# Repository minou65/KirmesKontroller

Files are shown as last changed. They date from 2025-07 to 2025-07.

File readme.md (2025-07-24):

# Kirmes kontroller
- [Kirmes kontroller](#kirmes-kontroller)
	- [Beschreibung](#beschreibung)
		- [Hauptfunktionen](#hauptfunktionen)
		- [Technische Spezifikationen](#technische-spezifikationen)
	- [Anschlüsse](#anschlüsse)
		- [Klemmenblöcke](#klemmenblöcke)
		- [Jumper-Einstellungen](#jumper-einstellungen)
	- [Controller](#controller)
	- [Librarys](#librarys)
	- [Pin mapping](#pin-mapping)
	- [internal pins](#internal-pins)
	- [external pins](#external-pins)
	- [Schema](#schema)
	- [Board](#board)
		- [Notwendige Änderungen auf v1 board](#notwendige-änderungen-auf-v1-board)
	- [Partliste](#partliste)
	- [Audio-Wiedergabe](#audio-wiedergabe)
		- [Unterstützte Audioformate](#unterstützte-audioformate)
		- [SD-Karte Setup](#sd-karte-setup)
		- [Kirmes-Sounds Quellen](#kirmes-sounds-quellen)
		- [Sounddateien bearbeiten](#sounddateien-bearbeiten)
			- [Online-Audio-Editoren](#online-audio-editoren)
			- [Desktop-Software](#desktop-software)
			- [Bearbeitungs-Tipps für Kirmes-Sounds](#bearbeitungs-tipps-für-kirmes-sounds)
			- [Batch-Verarbeitung](#batch-verarbeitung)
	- [Konfiguration](#konfiguration)
		- [System-Konfiguration](#system-konfiguration)
			- [System Configuration](#system-configuration)
			- [Sound Settings](#sound-settings)
			- [ServoOutput Konfiguration](#servooutput-konfiguration)
			- [Output Konfiguration](#output-konfiguration)
			- [Bedienelemente](#bedienelemente)
			- [Navigation](#navigation)
	- [WiFi](#wifi)
		- [Standard-Passwort](#standard-passwort)
		- [Standard-IP-Adresse](#standard-ip-adresse)
		- [OTA (Over-The-Air Updates)](#ota-over-the-air-updates)
		- [Konfigurationsoptionen](#konfigurationsoptionen)
		- [Blinkcodes](#blinkcodes)
	- [Firmware](#firmware)
		- [Firmware-Update über Web-Interface](#firmware-update-über-web-interface)
		- [Firmware-Update über OTA](#firmware-update-über-ota)
	- [Reset](#reset)
		- [Reset-Vorgang](#reset-vorgang)

## Beschreibung

Der KirmesKontroller ist ein vielseitiger NMRA-DCC-Decoder, der speziell für Kirmes- und Karussell-Anwendungen entwickelt wurde. Basierend auf dem leistungsstarken YB-ESP32-S3-AMP Mikrocontroller, bietet er umfangreiche Steuerungs- und Audio-Funktionen.

### Hauptfunktionen

**Ausgänge:**

- 8 digitale Ausgänge für Beleuchtung, Motoren und Effekte
- 3 Servo-Ausgänge für präzise Bewegungssteuerung
- Maximale Belastung: 500mA pro Ausgang

**Eingänge:**

- 2 digitale Eingänge für Taster- und Sensorfunktionen
- Manueller Betrieb unabhängig vom DCC-Signal möglich

**Konnektivität:**

- WiFi-Access-Point für direkten Zugriff
- Integration in bestehende WiFi-Netzwerke
- Web-basierte Konfigurationsoberfläche
- Over-The-Air (OTA) Updates

**Steuerungsmöglichkeiten:**

- **DCC-Kommandos:** Standard NMRA-DCC-Protokoll
- **Web-Interface:** Browserbasierte Steuerung
- **Digitale Eingänge:** Lokale Taster und Sensoren

**Audio-System:**

- Integrierte I2S-Audio-Wiedergabe
- SD-Karten-Unterstützung für Sounddateien
- Vielfältige Audioformate (MP3, WAV, FLAC, etc.)

### Technische Spezifikationen

**Stromversorgung:**

- **DC-Betrieb:** 8-28V Gleichspannung
- **AC-Betrieb:** 18-36V Wechselspannung
- **Ausgangsleistung:** 500mA pro Kanal
- **Wichtiger Hinweis:** Bei Jumper J1 auf Position "5V" darf der Gesamtstrom 1A nicht überschreiten

**Abmessungen und Anschlüsse:**

- Kompakte Bauform für einfache Integration
- Schraubklemmen für sichere Verbindungen
- Status-LEDs für visuelles Feedback

## Anschlüsse

### Klemmenblöcke

| Klemme | Beschreibung | Spezifikation |
|---|---|---|
| **X1** | Versorgungsspannung | 8-28V DC / 18-36V AC |
| **X2** | DCC-Signal | NMRA-DCC-Eingang |
| **X3** | Verbraucher (-) | Gemeinsamer Minuspol |
| **X4** | Verbraucher (+) | 5V/12-28V DC (abhängig von J1) |
| **X5-X7** | Servo-Anschlüsse | PWM-Ausgänge für Servos |
| **X8** | Digitale Eingänge | Input 1 und 2 |

### Jumper-Einstellungen

**J1 - Ausgangsspannung:**

- Position "5V": Ausgänge mit 5V (max. 1A Gesamtstrom)
- Position "VIN": Ausgänge mit Eingangsspannung (max. 500mA pro Ausgang)

## Controller

[YB-ESP32-S3-AMP](https://github.com/yellobyte/YB-ESP32-S3-AMP)

## Librarys

- [ESP32-audioI2S](https://github.com/schreibfaul1/ESP32-audioI2S) - Audio-Wiedergabe über I2S
- [IotWebConf](https://github.com/prampec/IotWebConf) - Web-Konfigurationsoberfläche
- [ArduinoOTA](https://github.com/esp8266/Arduino/tree/master/libraries/ArduinoOTA) - Over-The-Air Updates

## Pin mapping

## internal pins

```c++
#define SD_CS         10 
#define SPI_MOSI      11
#define SPI_MISO      13
#define SPI_SCK       12
#define I2S_DOUT       7
#define I2S_BCLK       5
#define I2S_LRCLK      6
#define LED_BUILTIN   47

#define DCC_INPUT     40
#define WIFI_RESET    39

```

## external pins

```c++
static uint8_t ChannelToGPIOMapping[8] = {
	17, // O11
	16, // O12
	15, // O13
	14, // O14
	10, // O15
	9,  // O16
	8,  // O17
	4  // O18
};

static uint8_t ServoChannelToGPIOMapping[3] = {
	2, // O21
	42, // O22
	41 // O23
};

#define INPUT1        21
#define INPUT2        38
```

## Schema

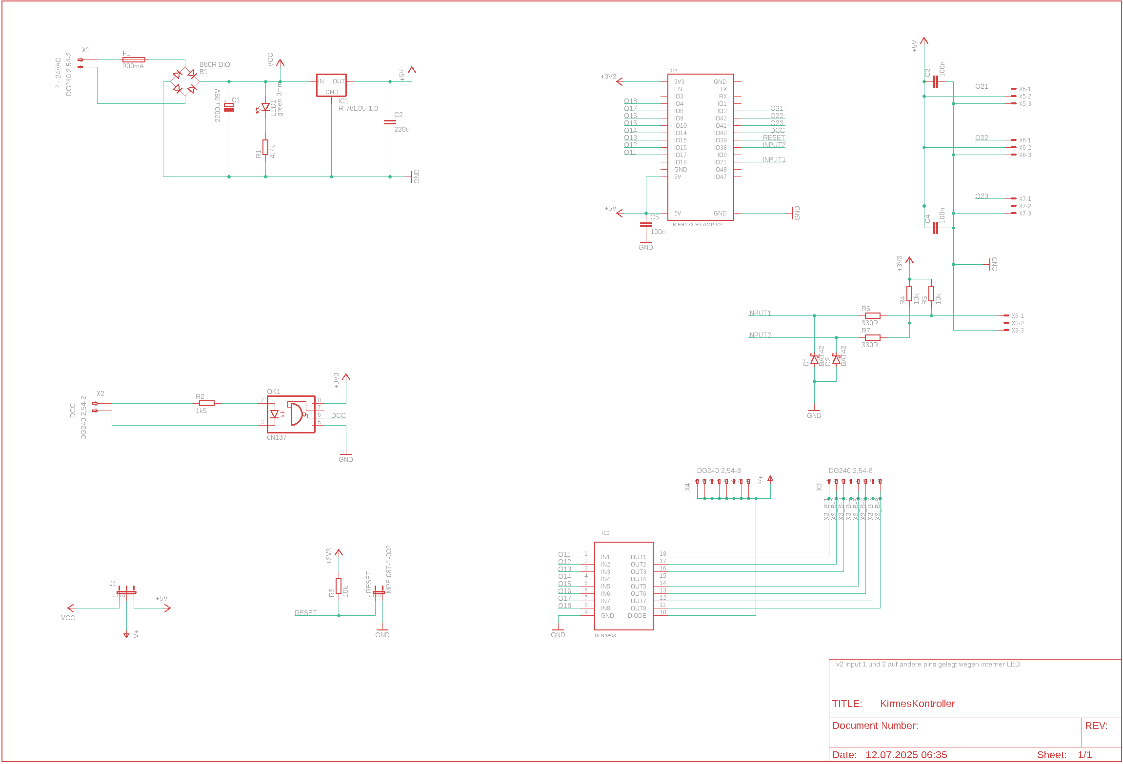
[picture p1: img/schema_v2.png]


## Board

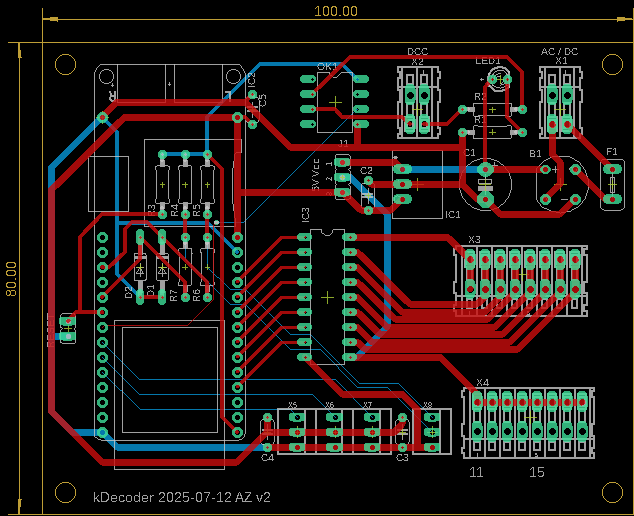
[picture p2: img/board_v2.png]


### Notwendige Änderungen auf v1 board

## Partliste

| Part | Value |
|---|---|
| B1 | B80R DIO |
| C1 | 2200u 35V |
| C2 | 220u |
| C3 | 100n |
| C4 | 100n |
| C5 | 100n |
| D1 | BAT42 |
| D2 | BAT42 |
| F1 | 900mA |
| IC1 | R-78E05-1.0 |
| IC2 | YB-ESP32-S3-AMP-V2 |
| IC3 | ULN2803 |
| J1 | MPE 087-1-003 |
| LED1 | green 3mm |
| OK1 | 6N137 |
| R1 | 4.7k |
| R2 | 1k5 |
| R3 | 10k |
| R4 | 10k |
| R5 | 10k |
| R6 | 330R |
| R7 | 330R |
| RESET | MPE 087-1-002 |
| X1 | DG240 2,54-2 |
| X2 | DG240 2,54-2 |
| X3 | DG240 2,54-8 |
| X4 | DG240 2,54-8 |
| X5 | 22-23-2031 |
| X6 | 22-23-2031 |
| X7 | 22-23-2031 |
| X8 | 22-23-2031 |

## Audio-Wiedergabe

Der KirmesKontroller unterstützt die Wiedergabe von Sounddateien über das integrierte I2S-Interface. Die Audiodaten werden von einer SD-Karte gelesen und über den angeschlossenen Verstärker ausgegeben.

### Unterstützte Audioformate

| Format | Spezifikation | Bemerkungen |
|---|---|---|
| **MP3** | Standard | Vollständig unterstützt |
| **AAC** | Standard | Vollständig unterstützt |
| **AACP** | Mono | Nur Mono-Wiedergabe |
| **WAV** | 8/16 Bit | Bits per Sample: 8 oder 16 |
| **FLAC** | Verlustfrei | Blockgrösse max. 24.576 Bytes |
| **Vorbis** | ≤196 kBit/s | Bitrate-Begrenzung beachten |
| **M4A** | Standard | Vollständig unterstützt |

### SD-Karte Setup

Die Audiodateien müssen auf einer SD-Karte gespeichert werden.

**Empfohlene SD-Karten-Struktur:**

```text
/sounds/
├── ambient/
│   ├── carousel.mp3
│   └── fairground.wav
├── effects/
│   ├── bell.mp3
│   └── whistle.wav
└── music/
    ├── waltz.mp3
    └── polka.mp3
```

### Kirmes-Sounds Quellen

Für authentische Kirmes- und Karussell-Sounds:

- **Pond5:** [Karussell & Kirmes Sounds](https://www.pond5.com/de/search?kw=karussell-unterhaltung-park-kirmes&media=sfx)
- **Freesound.org:** Community-basierte Sammlung von Soundeffekten
- **YouTube Audio Library:** Kostenlose Hintergrundmusik und Effekte

### Sounddateien bearbeiten

Für die optimale Nutzung mit dem KirmesKontroller sollten Audiodateien entsprechend bearbeitet werden. Hier sind einige nützliche Tools und Tipps:

#### Online-Audio-Editoren

**Audio Cutter** - Kostenloser Online-Editor für MP3-Dateien:

- **Features:** Schneiden, Trimmen, Fade-In/Out, Lautstärke anpassen
- **Formate:** MP3, WAV, M4A, FLAC, OGG, AMR, MP4
- **Link:** [Audio Cutter](https://www.audiocutter.org/de/mp3-cutter-online)

**TwistedWave Online** - Erweiterte Audio-Bearbeitung:

- **Features:** Mehrspur-Bearbeitung, Effekte, Normalisierung
- **Formate:** WAV, MP3, AIFF, FLAC, OGG
- **Link:** [TwistedWave](https://twistedwave.com/online/)

#### Desktop-Software

**Audacity** (Kostenlos):

- Professionelle Audio-Bearbeitung
- Unterstützt alle gängigen Formate
- Plugins für Spezialeffekte
- **Download:** [audacityteam.org](https://www.audacityteam.org/)

#### Bearbeitungs-Tipps für Kirmes-Sounds

**Loops erstellen:**

- Nahtlose Wiederholungen für Hintergrundmusik
- Fade-Out am Ende und Fade-In am Anfang vermeiden Knackgeräusche
- Optimale Loop-Länge: 30-120 Sekunden

**Lautstärke normalisieren:**

- Alle Sounds auf einheitliche Lautstärke bringen
- Empfohlener Pegel: -6 dB bis -3 dB
- Vermeidung von Clipping (Übersteuerung)

**Dateioptimierung:**

- **MP3:** 128-320 kBit/s für gute Qualität
- **WAV:** 16 Bit, 44.1 kHz für unkomprimierte Qualität
- **Dateiname:** Kurze, aussagekräftige Namen ohne Sonderzeichen

#### Batch-Verarbeitung

Für grössere Sammlungen:

- **FFmpeg** (Kommandozeilen-Tool) für automatische Konvertierung
- **Audacity** mit Makros für wiederkehrende Bearbeitungen
- **Format Factory** für Windows-Nutzer

## Konfiguration

Die Konfiguration des KirmesKontrollers erfolgt über das Web-Interface, das unter der IP-Adresse des Geräts erreichbar ist. Nach der erfolgreichen Verbindung können Sie auf die Konfigurationsseite zugreifen.

### System-Konfiguration

Die System-Konfiguration ist über `http://[IP-Adresse]/config` erreichbar und bietet folgende Einstellungsmöglichkeiten:

#### System Configuration

**Thing name:**
- Name des KirmesKontrollers (z.B. `kDecoder`)
- Eindeutige Identifikation im Netzwerk

**AP password:**
- Passwort für den Access Point Modus
- Wird verwendet, wenn keine WLAN-Verbindung besteht

**WiFi SSID:**
- Name des WLAN-Netzwerks (z.B. `1000-2575`)
- Netzwerk für die Internetverbindung

**WiFi password:**
- Passwort für das WLAN-Netzwerk

**Startup delay (seconds):**
- Verzögerung beim Start in Sekunden (z.B. `5`)
- Zeit bis zur vollständigen Initialisierung

#### Sound Settings

**Volume:**
- Lautstärke-Einstellung (0-21, z.B. `5`)
- Globale Audio-Lautstärke

**Mono:**
- Mono-Audio-Wiedergabe aktivieren/deaktivieren

**Balance:**
- Stereo-Balance-Einstellung (z.B. `0`)
- Links (16) / Rechts (-16) -Verteilung der Audio-Ausgabe

#### ServoOutput Konfiguration

Für jeden Servo-Ausgang können folgende Parameter konfiguriert werden:

**Designation:**
- Bezeichnung des Servos (z.B. `Karussel`)
- Beschreibender Name für die Identifikation

**Mode:**
- Betriebsmodus (z.B. `Motor (1)`)
- Definiert das Verhalten des Servo-Ausgangs

**DCC Address:**
- DCC-Adresse für die Steuerung (z.B. `3`)
- NMRA-DCC-Protokoll-Adresse

**Start delay (ms):**
- Startverzögerung in Millisekunden (z.B. `130`)
- Verzögerung vor der Aktivierung

**Multiplier:**
- Multiplikator für die Geschwindigkeit (z.B. `20`)
- Faktor zur Geschwindigkeitsanpassung

**Motor Speed:**
- Motorgeschwindigkeit (0-255, z.B. `255`)
- PWM-Wert für die Geschwindigkeit

**Filename:**
- Audio-Datei (z.B. `/carousel-sound-looped.mp3`)
- Sound-Datei von der SD-Karte

**Active Duration (ms):**
- Aktive Dauer in Millisekunden (z.B. `30000`)
- Laufzeit des Effekts

**Input Pin:**
- Zugeordneter Eingang (z.B. `Input1`)
- Digitaler Eingang für manuelle Steuerung

#### Output Konfiguration

Für jeden digitalen Ausgang können folgende Parameter konfiguriert werden:

**Designation:**
- Bezeichnung des Ausgangs (z.B. `Feuer`)
- Beschreibender Name

**Mode:**
- Betriebsmodus (z.B. `Feuer (3)`)
- Spezifischer Effekt-Modus

**DCC Address:**
- DCC-Adresse (z.B. `3`)
- Steuerungsadresse

**Brightness:**
- Helligkeit (0-255, z.B. `255`)
- PWM-Wert für die Helligkeit

**Filename:**
- Audio-Datei (optional)
- Begleitender Sound-Effekt

**Active Duration (ms):**
- Aktive Dauer (z.B. `1000`)
- Laufzeit des Effekts

**Input Pin:**
- Zugeordneter Eingang (z.B. `-` für nicht zugeordnet)
- Manuelle Steuerung

#### Bedienelemente

**+ ServoOutput:**
- Neuen Servo-Ausgang hinzufügen

**+ Output:**
- Neuen digitalen Ausgang hinzufügen

**Remove this set:**
- Konfiguration löschen

**Apply:**
- Einstellungen speichern und anwenden

#### Navigation

**Home:**
- Zur Hauptseite zurückkehren

**Reset:**
- System zurücksetzen

**Firmware update:**
- Firmware-Update durchführen

## WiFi

### Standard-Passwort

Wenn nicht mit einem AP verbunden, ist das Standardpasswort `123456789`

### Standard-IP-Adresse

Wenn nicht mit einem AP verbunden, ist die IP-Adresse `192.168.4.1`

### OTA (Over-The-Air Updates)

OTA ist aktiviert und kann verwendet werden. Damit ist es möglich, die Software des KirmesKontrollers zu updaten ohne unter die Anlage kriechen zu müssen. Die IP-Adresse ist entweder die Standard-IP-Adresse oder die vom AP zugewiesene. Port ist Standard.

### Konfigurationsoptionen

Nach dem ersten Start müssen einige Werte eingerichtet werden:

| Parameter | Beschreibung |
|---|---|
| **Thing name** | Name des Decoders. Es sollten keine Sonderzeichen und Umlaute verwendet werden. Punkte und Leerzeichen sollten ebenfalls nicht verwendet werden. |
| **AP password** | Dieses Passwort wird verwendet, wenn Sie später auf das Gerät zugreifen möchten. Sie müssen ein Passwort mit mindestens 8, höchstens 32 Zeichen verwenden. Es steht Ihnen frei, beliebige Zeichen zu verwenden. Es sollte ein Passwort mit mindestens 12 Zeichen Länge gewählt werden. |
| **WiFi SSID** | Name des WLAN mit welchem der KirmesKontroller verwendet werden soll. |
| **WiFi password** | Das Passwort zum Netzwerk, mit welchem der KirmesKontroller verbunden werden soll. |

### Blinkcodes

Die nachfolgende Tabelle fasst die verschiedenen Blinkcodes der Status-LED zusammen:

| Blinkcode | Bedeutung |
|---|---|
| **Rasches Blinken** | Meistens ein, unterbrochen durch kurze Aus-Perioden. Eigener AP ist aktiviert und Sie können mit dem Smartphone oder einem Computer eine Verbindung zum KirmesKontroller herstellen. |
| **Wechselblinken** | Der KirmesKontroller versucht mit einem AP zu verbinden. |
| **Langsames Blinken** | Meistens aus mit kurzem Blinken. Der KirmesKontroller ist online und mit dem WLAN verbunden. |

## Firmware

Hier kann, eine entsprechende Datei vorausgesetzt, die Firmware des KirmesKontrollers aktualisiert werden.

### Firmware-Update über Web-Interface

1. Navigieren Sie zur Web-Oberfläche des KirmesKontrollers
2. Wählen Sie die entsprechende Firmware-Datei (*.bin)
3. Starten Sie den Upload-Vorgang
4. Warten Sie, bis der Update-Prozess abgeschlossen ist
5. Das Gerät startet automatisch neu

### Firmware-Update über OTA

- Verwenden Sie die Arduino IDE oder PlatformIO
- Verbinden Sie sich mit der IP-Adresse des KirmesKontrollers
- Laden Sie die neue Firmware direkt hoch

## Reset

Wurde das Passwort vergessen oder funktioniert der KirmesKontroller nicht mehr, kann durch Schliessen des Jumpers RESET während dem Booten der Decoder auf die Werkseinstellungen zurückgesetzt werden.

### Reset-Vorgang

1. **Gerät ausschalten**
2. **RESET-Jumper schliessen** (siehe Platine)
3. **Gerät einschalten** und 10 Sekunden warten
4. **RESET-Jumper öffnen**
5. **Gerät neu starten**

Nach dem Reset sind folgende Standardwerte aktiv:

- **WiFi-Modus:** Access Point
- **SSID:** KirmesKontroller-[MAC]
- **Passwort:** 123456789
- **IP-Adresse:** 192.168.4.1
- **Alle Konfigurationen:** Zurückgesetzt

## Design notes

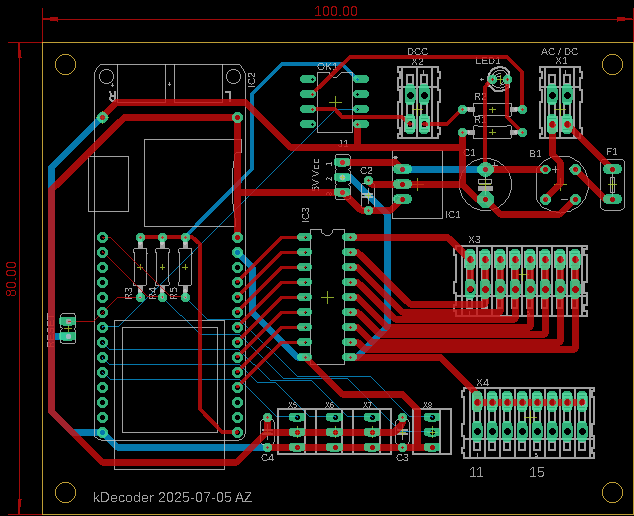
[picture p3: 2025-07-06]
img/board.png

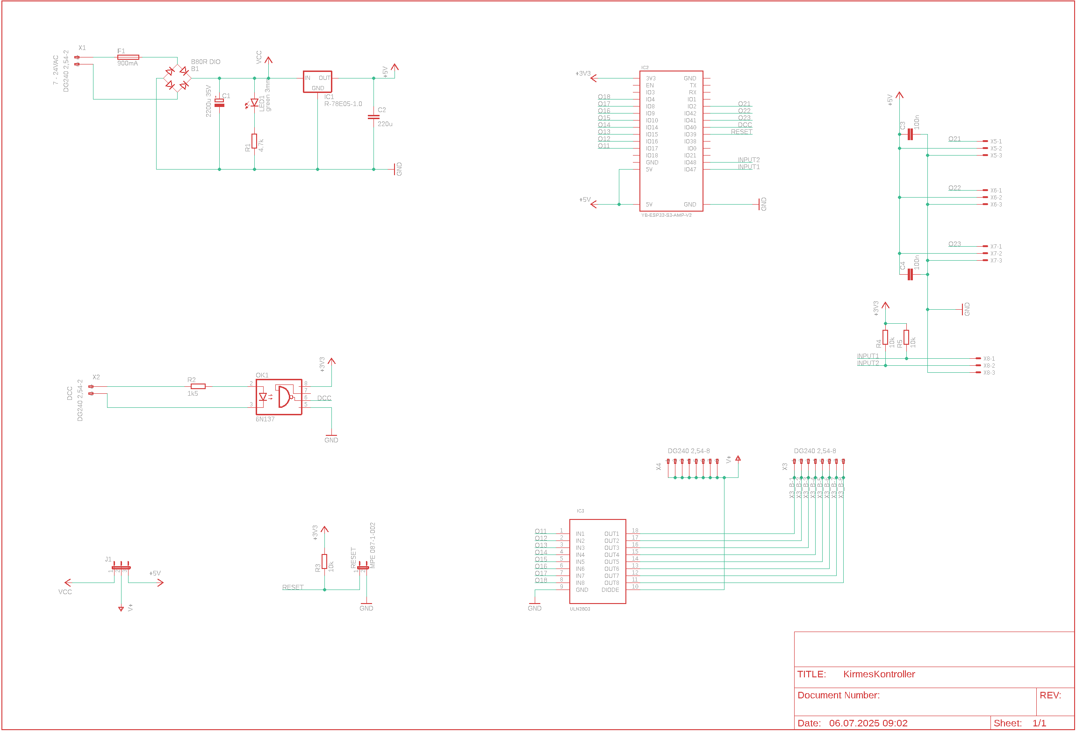
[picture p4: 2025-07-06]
img/schema.png

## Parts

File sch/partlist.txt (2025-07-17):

Partlist

Exported from KirmesKontroller.brd at 16.07.2025 18:35

EAGLE Version 9.6.2 Copyright (c) 1988-2020 Autodesk, Inc.

Assembly variant: 

Part     Value              Package         Library         Position (mm)         Orientation

B1       B80R DIO           RB1A            rectifier       (87.63 55.88)         R0
C1       2200u 35V          E5-8,5          rcl             (74.93 55.88)         R270
C2       220u               C050-024X044    rcl             (55.118 53.975)       R90
C3       100n               C050-024X044    rcl             (60.96 13.97)         R270
C4       100n               C050-024X044    rcl             (38.1 13.97)          R270
C5       100n               C050-024X044    rcl             (35.56 68.58)         R90
D1       BAT42              DO35-10         diode           (20.32 41.91)         R270
D2       BAT42              DO35-10         diode           (16.51 41.91)         R270
F1       900mA              TE5             fuse            (96.52 55.88)         R270
IC1      R-78E05-1.0        R-78E-XX1.0     _eigene         (63.5 55.88)          R270
IC2      YB-ESP32-S3-AMP-V2 YB-ESP32-S3-AMP yb-esp32-s3-amp (10.16 67.31)         R270
IC3      ULN2803            DIL18           _eigene         (48.26 36.83)         R270
J1       MPE 087-1-003      JP2             jumper          (50.8 57.15)          R270
LED1     green 3mm          LED3MM          led             (77.47 73.66)         R0
OK1      6N137              DIL08           optocoupler     (49.53 69.85)         R270
R1       4.7k               0207/10         rcl             (76.2 64.77)          R0
R2       1k5                0207/10         rcl             (76.2 68.58)          R0
R3       10k                0207/10         rcl             (20.32 55.88)         R90
R4       10k                0207/10         rcl             (24.13 55.88)         R90
R5       10k                0207/10         rcl             (27.94 55.88)         R90
R6       330R               0207/10         rcl             (27.94 41.91)         R90
R7       330R               0207/10         rcl             (24.13 41.91)         R90
RESET    MPE 087-1-002      JP1             jumper          (4.318 31.496)        R180
X1       DG240 2,54-2       233-202         con-wago255     (87.63 68.58)         R180
X2       DG240 2,54-2       233-202         con-wago255     (63.5 68.58)          R180
X3       DG240 2,54-8       233-508         con-wago255     (81.28 40.64)         R0
X4       DG240 2,54-8       233-508         con-wago255     (82.55 16.51)         R0
X5       22-23-2031         22-23-2031      con-molex       (43.18 13.97)         R270
X6       22-23-2031         22-23-2031      con-molex       (49.53 13.97)         R270
X7       22-23-2031         22-23-2031      con-molex       (55.88 13.97)         R270
X8       22-23-2031         22-23-2031      con-molex       (66.04 13.97)         R270

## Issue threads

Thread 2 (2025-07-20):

ServoControl::ServoControl(int8_t Channel_, int limit1_, int limit2_, int travelTime_, unsigned int flags_)

minou65, 2025-07-20:
_servo.attach(_GPIO, 500, 2400); erfolgt mit festen Werten

  myservo.attach(servoPin, 500, 2400);   // attaches the servo on pin 18 to the servo object
                                         // using SG90 servo min/max of 500us and 2400us
                                         // for MG995 large servo, use 1000us and 2000us,
                                         // which are the defaults, so this line could be
                                         // "myservo.attach(servoPin);"

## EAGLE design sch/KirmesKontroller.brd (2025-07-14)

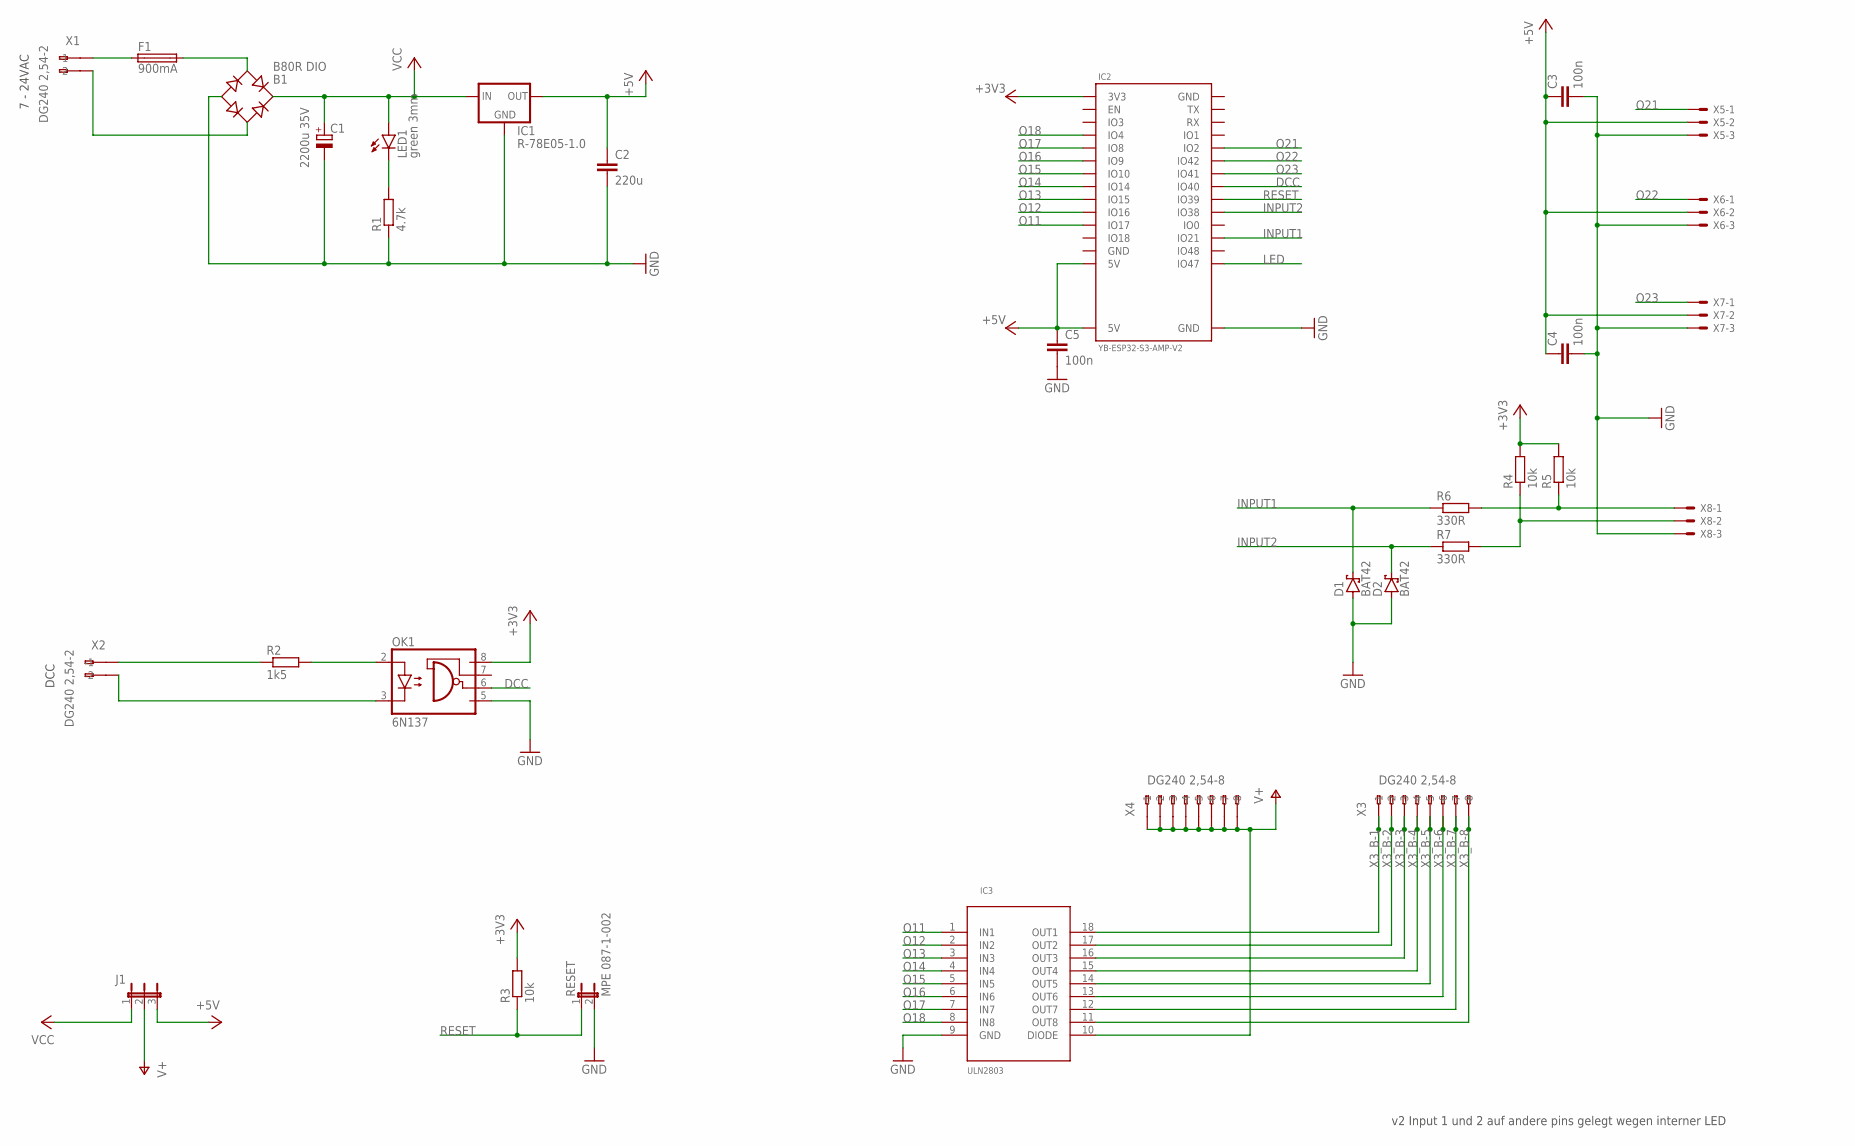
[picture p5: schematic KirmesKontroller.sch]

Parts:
B1: B80R DIO; RB1A
C1: 2200u 35V; E5-8,5
C2: 220u; C050-024X044
C3, C4, C5: 100n; C050-024X044
D1, D2: BAT42; DO35-10
F1: 900mA; TE5
IC1: R-78E05-1.0; R-78E-XX1.0
IC2: YB-ESP32-S3-AMP-V2; YB-ESP32-S3-AMP
IC3: ULN2803; DIL18
J1: MPE 087-1-003; JP2
LED1: green 3mm; LED3MM
OK1: 6N137; DIL08
R1: 4.7k; 0207/10
R2: 1k5; 0207/10
R3, R4, R5: 10k; 0207/10
R6, R7: 330R; 0207/10
RESET: MPE 087-1-002; JP1
X1, X2: DG240 2,54-2; 233-202
X3, X4: DG240 2,54-8; 233-508
X5, X6, X7, X8: 22-23-2031

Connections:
+3V3: IC2.3V3, OK1.8 (VCC), R3.2, R4.2, R5.2
+5V: C2.1, C3.1, C4.1, C5.1, IC1.OUT, IC2.5V, IC2.5V@1 (5V), J1.3, X5.2, X6.2, X7.2
DCC: IC2.40 (IO40), OK1.6 (VO)
GND: B1.-, C1.-, C2.2, C3.2, C4.2, C5.2, D1.A, D2.A, IC1.GND, IC2.GND, IC2.GND@1 (GND), IC2.GND@2 (GND), IC3.9 (GND), OK1.5 (GND), R1.1, RESET.2, X5.3, X6.3, X7.3, X8.3
INPUT1: D1.C, IC2.21 (IO21), R6.1
INPUT2: D2.C, IC2.38 (IO38), R7.1
LED: IC2.47 (IO47)
unnamed: R5.1, R6.2, X8.1
unnamed: R4.1, R7.2, X8.2
unnamed: LED1.K (C), R1.2
unnamed: B1.AC1, F1.2
unnamed: B1.AC2, X1.A2 (-2)
unnamed: R2.1, X2.A1 (-1)
unnamed: OK1.2 (A), R2.2
unnamed: OK1.3 (C), X2.A2 (-2)
unnamed: F1.1, X1.A1 (-1)
O11: IC2.17 (IO17), IC3.1 (IN1)
O12: IC2.16 (IO16), IC3.2 (IN2)
O13: IC2.15 (IO15), IC3.3 (IN3)
O14: IC2.14 (IO14), IC3.4 (IN4)
O15: IC2.10 (IO10), IC3.5 (IN5)
O16: IC2.9 (IO9), IC3.6 (IN6)
O17: IC2.8 (IO8), IC3.7 (IN7)
O18: IC2.4 (IO4), IC3.8 (IN8)
O21: IC2.2 (IO2), X5.1
O22: IC2.42 (IO42), X6.1
O23: IC2.41 (IO41), X7.1
RESET: IC2.39 (IO39), R3.1, RESET.1
V+: IC3.10 (DIODE), J1.2, X4.A1 (-1), X4.A2 (-2), X4.A3 (-3), X4.A4 (-4), X4.A5 (-5), X4.A6 (-6), X4.A7 (-7), X4.A8 (-8)
VCC: B1.+, C1.+, IC1.IN, J1.1, LED1.A
X3_B-1: IC3.18 (OUT1), X3.A1 (-1), X3.B1 (B-1)
X3_B-2: IC3.17 (OUT2), X3.A2 (-2), X3.B2 (B-2)
X3_B-3: IC3.16 (OUT3), X3.A3 (-3), X3.B3 (B-3)
X3_B-4: IC3.15 (OUT4), X3.A4 (-4), X3.B4 (B-4)
X3_B-5: IC3.14 (OUT5), X3.A5 (-5), X3.B5 (B-5)
X3_B-6: IC3.13 (OUT6), X3.A6 (-6), X3.B6 (B-6)
X3_B-7: IC3.12 (OUT7), X3.A7 (-7), X3.B7 (B-7)
X3_B-8: IC3.11 (OUT8), X3.A8 (-8), X3.B8 (B-8)

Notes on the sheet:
7 - 24VAC
DCC
v2 Input 1 und 2 auf andere pins gelegt wegen interner LED

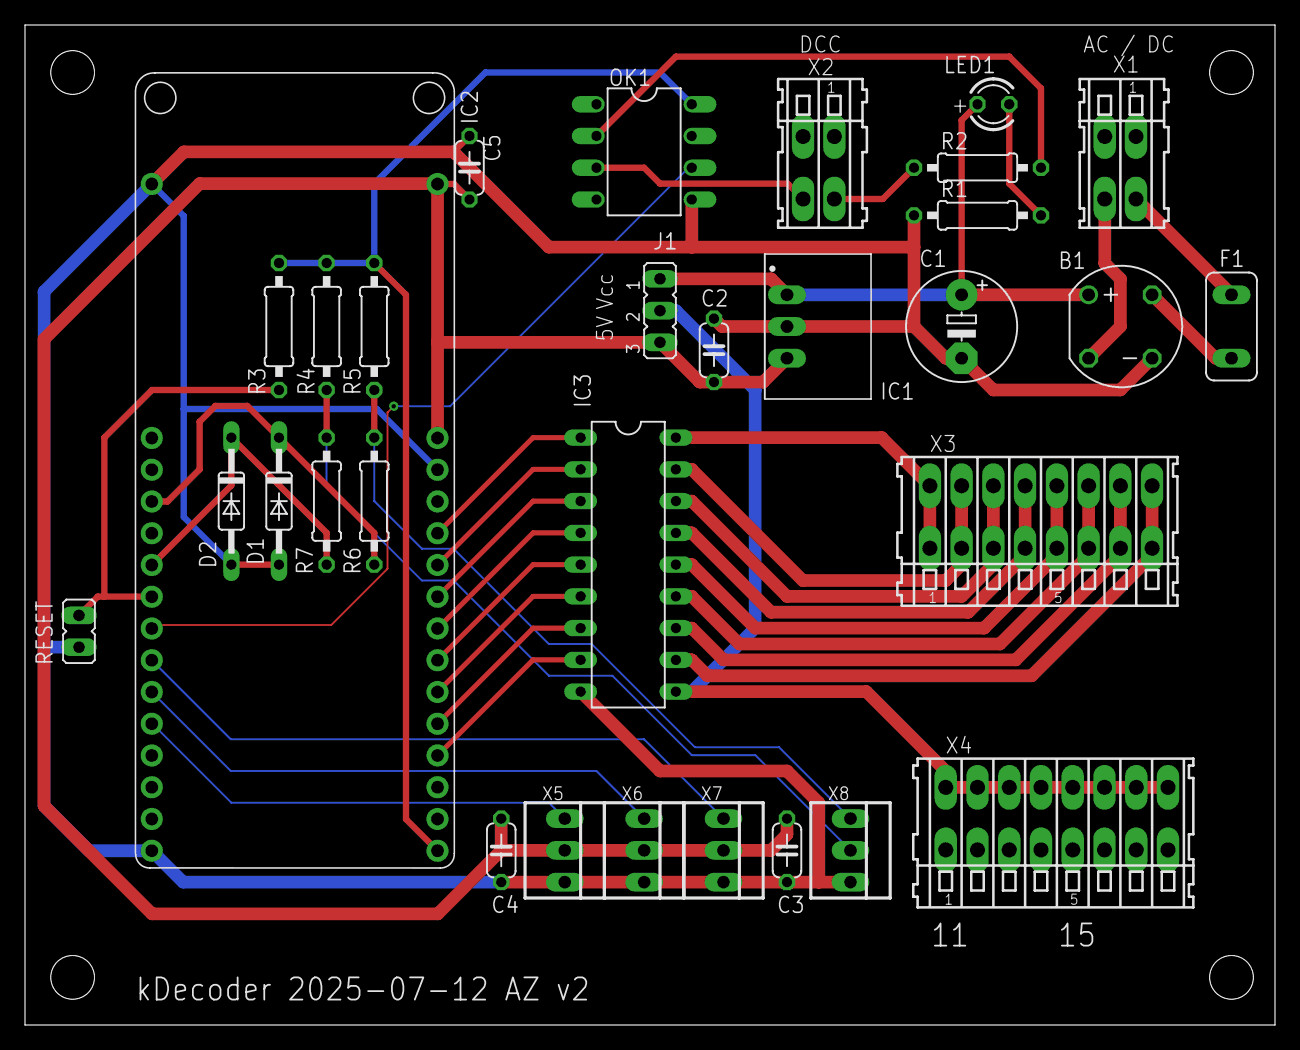
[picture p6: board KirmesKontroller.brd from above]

Board: 2 copper layers, 100.0 x 80.0 mm, 31 parts (0 on the bottom side), 37 nets.

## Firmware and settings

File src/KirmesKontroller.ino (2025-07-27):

// #define NOTIFY_DCC_ACCSTATE_MSG
// #define NOTIFY_DCC_MSG
// #define NOTIFY_TURNOUT_MSG
// #define NOTIFY_DCC_CV_WRITE_MSG
// #define NOTIFY_DCC_CV_CHANGE_MSG
// #define DEBUG_MSG

#include <Arduino.h>

#include "neotimer.h"
#include "version.h"
#include "pinmapping.h"
#include "Vector.h"
#include "SoundControl.h"
#include "accessories.h"
#include "webhandling.h"
#include "NMRAhandling.h"
#include "Outputhandling.h"
#include "Servohandling.h"
#include "Motorhandling.h"

char Version[] = VERSION_STR;

// Liste mit allen Decoderobjekten (Apps)
Vector<accessories*> decoder;

// Task handle (Core 0 on ESP32)
TaskHandle_t TaskHandle;

bool ResetDCCDecoder = false;

void notifyDccAccTurnoutOutput(uint16_t Addr, uint8_t Direction, uint8_t OutputPower) {
#ifdef  NOTIFY_TURNOUT_MSG
	Serial.print("notifyDccAccTurnoutOutput: Turnout: ");
	Serial.print(Addr, DEC);
	Serial.print(" Direction: ");
	Serial.print(Direction ? "Closed" : "Thrown");
	Serial.print(" Output: ");
	Serial.println(OutputPower ? "On" : "Off");
#endif

	for (int _i = 0; _i < decoder.Size(); _i++) {
		decoder[_i]->notifyTurnoutAddress(Addr, Direction, OutputPower);
	}
}

void notifyDccSpeed(uint16_t Addr, uint8_t Speed, uint8_t ForwardDir, uint8_t SpeedSteps) {
	for (int i = 0; i < decoder.Size(); i++) {

		// is it a Servo?
		if (decoder[i]->ChannelMode() == 230) {
			decoder[i]->notifyDccSpeed(Addr, Speed, ForwardDir, SpeedSteps);
		}
	}
}

void notifyDccAccState(uint16_t Addr, uint16_t BoardAddr, uint8_t OutputAddr, uint8_t State) {
	uint8_t _OutputNum = OutputAddr >> 1;  //shift over the bits so the outputaddr is 0 to 3
	uint8_t _Cmd = OutputAddr & 0b00000001;  //JMRI puts out the state as the right most bit of pDccMsg->Data[1], the state argument doesnt change in JMRI Turnout.

#ifdef NOTIFY_DCC_ACCSTATE_MSG
	Serial.print("AccState - ");
	Serial.print("Raw addr: ");
	Serial.print(Addr);
	Serial.print(" BoardAddr: ");
	Serial.print(BoardAddr, DEC);
	Serial.print(" OutputAddr: ");
	Serial.print(OutputAddr, DEC);
	Serial.print(" Output: ");
	Serial.print(_OutputNum);
	Serial.print(" State: 0b");
	Serial.print(State, BIN);
	Serial.print(" Command: ");
	Serial.print(_Cmd == 1 ? "Closed" : "Thrown");
	Serial.println();
	//Serial.print("    zDecoder: "); Serial.println(BoardAddr + OutputAddr);
#endif 

#ifdef  NOTIFY_TURNOUT_MSG
	Serial.print("zDecoder: Address"); Serial.print(Addr);
	Serial.print(_Cmd == 1 ? " :Closed" : " :Thrown");
	Serial.println();
#endif

	for (int _i = 0; _i < decoder.Size(); _i++) {
		decoder[_i]->notifyAddress(Addr, _Cmd);
	}
}

void notifyDccFunc(uint16_t Addr, uint8_t FuncNum, uint8_t FuncState) {

	if (FuncNum != 1)
		return;

	for (int i = 0; i < decoder.Size(); i++) {

		// is it a Servo?
		if (decoder[i]->ChannelMode() == 230) {
			if (FuncState & 0x10)
				decoder[i]->on();
			else
				decoder[i]->off();
		}
	}

	if (FuncNum != 1)
		return;
}

void handleDecoderGroup(uint8_t DecoderGroup) {
	Serial.print(F("Toggling decoder group: ")); Serial.println(DecoderGroup);
	if (DecoderGroupIsActive(DecoderGroup)) {
		Serial.println(F("    Decoder group is active, toggling state..."));
		if (decoder[DecoderGroup]->isOn()) {
			decoder[DecoderGroup]->off();
		}
		else {
			decoder[DecoderGroup]->on();
		}
	}
	else {
		Serial.println(F("    Decoder group is not active, cannot toggle state."));
	}
}

bool DecoderGroupIsEnabled(uint8_t DecoderGroup) {
	if (DecoderGroupIsActive(DecoderGroup)) {
		return decoder[DecoderGroup]->isOn();
	}
	else {
		return false;
	}
}

bool DecoderGroupIsActive(uint8_t DecoderGroup) {
#ifdef DEBUG_MSG
	Serial.print(F("[DEBUG] DecoderGroupIsActive: DecoderGroup="));
	Serial.print(DecoderGroup);
	Serial.print(F(", decoder.Size()="));
	Serial.print(decoder.Size());
	if (DecoderGroup < decoder.Size()) {
		Serial.print(F(", decoder[DecoderGroup] is "));
		Serial.println(decoder[DecoderGroup] != nullptr ? "not null" : "null");
	}
	else {
		Serial.println(F(", DecoderGroup out of range"));
	}
#endif
	if (DecoderGroup < decoder.Size() && decoder[DecoderGroup] != nullptr) {
		return true;
	}
	else {
		return false;
	}
}

void kDecoderReset() {
	OutputGroup* outputgroup_ = &OutputGroup1;
	while (outputgroup_ != nullptr) {
		outputgroup_->applyDefaultValues();
		outputgroup_->setActive(false);

		outputgroup_ = (OutputGroup*)outputgroup_->getNext();
	}

	ServoGroup* servogroup_ = &ServoGroup1;
	while (servogroup_ != nullptr) {
		servogroup_->applyDefaultValues();
		servogroup_->setActive(false);

		servogroup_ = (ServoGroup*)servogroup_->getNext();
	}
}

void kDecoderInit(void) {
	

	Serial.println("======== Initializing kdecoder... =========");

	// Decoderobjekte in decoder l�schen
	for (int i_ = 0; i_ < decoder.Size(); ++i_) {
		delete decoder[i_];
	}
	decoder.Erase(0, decoder.Size());
	decoder.Clear();
	Vector<accessories*>().Swap(decoder);

	Serial.println("======== Setting up outputs... =========");
	uint8_t OutputIndex_ = 0;
	OutputGroup* outputgroup_ = &OutputGroup1;
	while (outputgroup_ != nullptr) {
		if (OutputIndex_ >= MAX_OUTPUT_PINS) {
			Serial.println("no more free channels!");
			break;
		}

		uint8_t BasePin_ = OutputIndexToPin[OutputIndex_];

		if (outputgroup_->isActive()) {
			uint8_t Mode_ = outputgroup_->getMode();
			uint8_t Count_ = outputgroup_->getNumber();
			uint16_t Address_ = outputgroup_->getAddress();
			uint8_t TimeOn_ = outputgroup_->getTimeOn();
			uint8_t TimeOff_ = outputgroup_->getTimeOff();
			uint8_t Multiplier_ = outputgroup_->getMultiplier(); // Multiplikator
			uint8_t TimeOnFade_ = outputgroup_->getTimeOnFade();
			uint8_t TimeOffFade_ = outputgroup_->getTimeOffFade();
			uint8_t Brightness_ = outputgroup_->getBrightness();

			uint16_t DayLightAddress_ = 0;
			uint8_t DayBrightness_ = 255;
			uint8_t NightBrightness_ = 150;

			SoundSettings sound_;
			strncpy(sound_.filename, outputgroup_->getSoundFilename() ? outputgroup_->getSoundFilename() : "", sizeof(sound_.filename) - 1);
			sound_.filename[sizeof(sound_.filename) - 1] = '\0'; // Nullterminierung sicherstellen
			sound_.volume = soundGroup.getVolume();
			sound_.balance = soundGroup.getBalance();
			sound_.mono = soundGroup.isMono();

			Serial.print(F("Values for channel ")); Serial.print(BasePin_); Serial.println(F(" preserved"));
			Serial.print(F("    Pins used: ")); Serial.println(Count_);
			Serial.print(F("    Address: ")); Serial.println(Address_);
			Serial.print(F("    Base Pin: ")); Serial.println(BasePin_);

			// Einrichten des Ports
			accessories* newAccessory = nullptr;
			switch (Mode_) {
			case 0:
				newAccessory = new accessories(Address_, BasePin_);
				OutputIndex_ += Count_;
				break;
			case 40: // einfacher Ausgang
				newAccessory = new AusgangDelay(Address_, BasePin_, TimeOn_ * Multiplier_);
				OutputIndex_ += 1;
				break;
			case 50: // Blinker
				newAccessory = new Blinker(Address_, BasePin_, Multiplier_ * TimeOff_, Multiplier_ * TimeOn_, TimeOnFade_, TimeOffFade_, Mode_);
				OutputIndex_ += 1;
				break;
			case 51: // Wechselblinker
				newAccessory = new Wechselblinker(Address_, BasePin_, Multiplier_ * TimeOff_, Multiplier_ * TimeOn_, TimeOnFade_, TimeOffFade_);
				OutputIndex_ += 2;
				break;
			case 52: case 53: case 54: case 55: // diverse Lauflichter
				newAccessory = new Lauflicht(Address_, BasePin_, Count_, Multiplier_ * TimeOff_, Multiplier_ * TimeOn_, Mode_);
				OutputIndex_ += Count_;
				break;
			case 60: // Hausbeleuchtung
				newAccessory = new Hausbeleuchtung(Address_, BasePin_, Count_, Multiplier_ * TimeOff_, Multiplier_ * TimeOn_);
				OutputIndex_ += Count_;
				break;
			case 61: // Neonröhren
				newAccessory = new NeonLampen(Address_, BasePin_, Count_, Multiplier_);
				OutputIndex_ += Count_;
				break;
			case 62: // Natriumlampen
				newAccessory = new NatriumLampen(Address_, BasePin_, Count_, Multiplier_, TimeOnFade_, TimeOffFade_);
				OutputIndex_ += Count_;
				break;
			case 80: // TV
				newAccessory = new Fernseher(Address_, BasePin_);
				OutputIndex_ += 1;
				break;
			case 81: // Schweisslicht
				newAccessory = new Schweissen(Address_, BasePin_, Multiplier_ * TimeOff_, Multiplier_ * TimeOn_);
				OutputIndex_ += 3;
				break;
			case 82: // Feuer
				newAccessory = new Feuer(Address_, BasePin_);
				OutputIndex_ += 3;
				break;
			case 83: // Blitzlicht
				newAccessory = new Blitzlicht(Address_, BasePin_, TimeOnFade_ * 1000, TimeOffFade_ * 1000, TimeOn_ * Multiplier_, TimeOff_ * Multiplier_);
				OutputIndex_ += 1;
				break;
			case 203:// Motor
				newAccessory = new Motor(Address_, BasePin_, Mode_, TimeOn_ * Multiplier_); // Create a new Motor accessory
				OutputIndex_ += 1;
				break;
			}

			if (newAccessory != nullptr) {
				Serial.print(F("    Mode: ")); Serial.println(Mode_);

				Accessory* accessory = static_cast<Accessory*>(newAccessory);
				accessory->setSoundSettings(sound_);
				accessory->setInputPin(outputgroup_->getInputPin());
				accessory->setTimer(outputgroup_->getActiveDuration());

				// Check the type of newAccessory
				if (newAccessory->getType() == AccessoryType::LED) {
					Ausgang* ledAccessory = static_cast<Ausgang*>(newAccessory);
					// If the cast is successful, set the brightness
					ledAccessory->SetMaxBrightness(Brightness_);
				}
				decoder.PushBack(newAccessory);
			}
		}
		outputgroup_ = (OutputGroup*)outputgroup_->getNext();
	}

	ServoGroup* servogroup_ = &ServoGroup1;
	uint8_t ServoIndex_ = 0;
	Serial.println("======== Setting up servos... =========");
	while (servogroup_ != nullptr) {
		if (ServoIndex_ >= MAX_SERVO_PINS) {
			Serial.println("no more free pins!");
			break;
		}

		if(servogroup_->isActive()) {
			uint16_t Address_ = servogroup_->getAddress();
			uint8_t ServoPort_ = ServoIndexToPin[ServoIndex_];
			uint16_t limit1_ = servogroup_->getLimit1();
			uint16_t limit2_ = servogroup_->getLimit2();
			uint16_t travelTime_ = servogroup_->getTravelTime();
			uint16_t multiplier_ = servogroup_->getMultiplier();
			uint16_t timeOn_ = servogroup_->getTimeOn();
			uint16_t timeOff_ = servogroup_->getTimeOff();
			uint16_t Mode_ = servogroup_->getMode();

			SoundSettings sound_;
			strncpy(sound_.filename, servogroup_->getSoundFilename() ? servogroup_->getSoundFilename() : "", sizeof(sound_.filename) - 1);
			sound_.filename[sizeof(sound_.filename) - 1] = '\0'; // Nullterminierung sicherstellen
			sound_.volume = soundGroup.getVolume();
			sound_.balance = soundGroup.getBalance();
			sound_.mono = soundGroup.isMono();

			Serial.print(F("Values for Servo ")); Serial.print(ServoIndex_); Serial.println(F(" preserved"));
			Serial.print(F("    Mode: ")); Serial.println(Mode_);
			Serial.print(F("    Address: ")); Serial.println(Address_);

			// Einrichten des Ports
			accessories* newAccessory_ = nullptr;
			switch (Mode_) {
			case 251: // Servo Impulse
				newAccessory_ = new ServoImpulseAccessory(Address_, ServoPort_, limit1_, limit2_, travelTime_ * multiplier_, timeOn_);
				ServoIndex_++;
				break;
			case 252: // Servo Flip
				newAccessory_ = new ServoFlipAccessory(Address_, ServoPort_, limit1_, limit2_, travelTime_ * multiplier_);
				ServoIndex_++;
				break;
			case 253: // Servo Pendel
				newAccessory_ = new ServoPendelAccessory(Address_, ServoPort_, limit1_, limit2_, travelTime_ * multiplier_, timeOn_, timeOff_);
				ServoIndex_++;
				break;
			}

			if (newAccessory_ != nullptr) {
				Accessory* accessory_ = static_cast<Accessory*>(newAccessory_);
				accessory_->setSoundSettings(sound_);
				accessory_->setInputPin(servogroup_->getInputPin());
				accessory_->setTimer(servogroup_->getActiveDuration());

				decoder.PushBack(newAccessory_);
				Serial.print(F("    Mode: ")); Serial.println(servogroup_->getMode());
				Serial.print(F("    ServoIndex: ")); Serial.println(ServoIndex_);
			}
			else {
				Serial.println(F("    No valid servo mode found, skipping this group."));
			}
		}

		if (servogroup_->isActive()) {
		}
		
		servogroup_ = (ServoGroup*)servogroup_->getNext();
	}

	

	Serial.println("======== kdecoder initialized =========");
	Serial.print("Decoder size: "); Serial.println(decoder.Size());
	Serial.print("Output pin used: "); Serial.println(OutputIndex_);
	Serial.print("Servo pin used: "); Serial.println(ServoIndex_);
}

void setup() {
	Serial.begin(115200);
	while (!Serial) {
		delay(10);
	}

	Serial.println("Starting with Firmware " + String(VERSION));

	setupWeb(); // Set up web handling
	setupSound(); // Set up sound system
	NMRAsetup();

	kDecoderInit(); // Initialize the decoder

	if (CONFIG_PIN >= 0) {
		pinMode(CONFIG_PIN, INPUT);
		if (digitalRead(CONFIG_PIN) == LOW) {
			Serial.println("config pin was pressed, reset decoder");
			kDecoderReset();
		}
	}

	xTaskCreatePinnedToCore(
		loop2, /* Function to implement the task */
		"TaskHandle", /* Name of the task */
		10000,  /* Stack size in words */
		NULL,  /* Task input parameter */
		0,  /* Priority of the task */
		&TaskHandle,  /* Task handle. */
		0 /* Core where the task should run */
	);

	Serial.println("Everything has been initialized");
}

void loop() {
	NMRAloop(); // Handle NMRA DCC messages
	loopWeb(); // Handle web requests
	loopSound(); // Handle sound playback
}

void loop2(void* parameter) {

	for (;;) {   // Endless loop
		if (ResetDCCDecoder) {
			kDecoderInit();
			ResetDCCDecoder = false;
		}

		for (int _i = 0; _i < decoder.Size(); _i++) {
			decoder[_i]->process();
		}
	}
}

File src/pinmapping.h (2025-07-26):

// pinmapping.h

#ifndef _PINMAPPING_h
#define _PINMAPPING_h

#if defined(ARDUINO) && ARDUINO >= 100
	#include "arduino.h"
#else
	#include "WProgram.h"
#endif

static uint8_t OutputIndexToPin[8] = {
	17, // O11
	16, // O12
	15, // O13
	14, // O14
	10, // O15
	9,  // O16
	8,  // O17
	4  // O18
};

const size_t MAX_OUTPUT_PINS = sizeof(OutputIndexToPin) / sizeof(OutputIndexToPin[0]);

static uint8_t ServoIndexToPin[3] = {
	2, // O21
	42, // O22
	41, // O23
};

const size_t MAX_SERVO_PINS = sizeof(ServoIndexToPin) / sizeof(ServoIndexToPin[0]);

#define INPUT1        21
#define INPUT2        38

#define SD_CS         10 
#define SPI_MOSI      11
#define SPI_MISO      13
#define SPI_SCK       12
#define I2S_DOUT       7
#define I2S_BCLK       5
#define I2S_LRCLK      6
#define LED_BUILTIN   47

#define DCC_INPUT     40
#define CONFIG_PIN    39

#endif

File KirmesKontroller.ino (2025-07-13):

#include <Arduino.h>

#include "src/neotimer.h"
#include "src/version.h"
#include "src/MotorControl.h"
#include "src/SoundControl.h"
#include "src/Blinkers.h"
#include "src/pinmapping.h"
#include "src/Vector.h"
#include "src/accessories.h"
#include "src/webhandling.h"

char Version[] = VERSION_STR;

// Liste mit allen Decoderobjekten (Apps)
Vector<accessories*> decoder;

bool ResetDCCDecoder = false;

void handleDecoderGroup(uint8_t DecoderGroup) {
	if (DecoderGroupIsActive(DecoderGroup)) {
		if (decoder[DecoderGroup]->isOn()) {
			decoder[DecoderGroup]->off();
		}
		else {
			decoder[DecoderGroup]->on();
		}
	}
}

bool DecoderGroupIsEnabled(uint8_t DecoderGroup) {
	if (DecoderGroupIsActive(DecoderGroup)) {
		return decoder[DecoderGroup]->isOn();
	}
	else {
		return false;
	}
}

bool DecoderGroupIsActive(uint8_t DecoderGroup) {
	if (DecoderGroup < decoder.Size() && decoder[DecoderGroup] != nullptr) {
		return true;
	}
	else {
		return false;
	}
}

void kDecoderReset() {
	OutputGroup* outputgroup_ = &OutputGroup1;
	while (outputgroup_ != nullptr) {
		outputgroup_->_DesignationParam.applyDefaultValue();
		outputgroup_->_ModeParam.applyDefaultValue();
		outputgroup_->_NumberParam.applyDefaultValue();
		outputgroup_->_AddressParam.applyDefaultValue();
		outputgroup_->_TimeOnParam.applyDefaultValue();
		outputgroup_->_TimeOffParam.applyDefaultValue();
		outputgroup_->_TimeOnFadeParam.applyDefaultValue();
		outputgroup_->_TimeOffFadeParam.applyDefaultValue();
		outputgroup_->setActive(false);

		outputgroup_ = (OutputGroup*)outputgroup_->getNext();
	}

	ServoGroup* servogroup_ = &ServoGroup1;
	while (servogroup_ != nullptr) {
		servogroup_->_designationParam.applyDefaultValue();
		servogroup_->_addressParam.applyDefaultValue();
		servogroup_->_travelTimeParam.applyDefaultValue();
		servogroup_->_limit1Param.applyDefaultValue();
		servogroup_->_limit2Param.applyDefaultValue();
		servogroup_->setActive(false);

		servogroup_ = (ServoGroup*)servogroup_->getNext();
	}
}

void kDecoderInit(void) {
	uint8_t channel_ = 0;

	// Decoderobjekte in decoder löschen
	decoder.Erase(0, decoder.Size());
	decoder.Clear();
	Vector<accessories*>().Swap(decoder);

	OutputGroup* outputgroup_ = &OutputGroup1;
	while (outputgroup_ != nullptr) {
		if (channel_ > 15) {
			Serial.println("no more free channels!");
			break;
		}

		if (outputgroup_->isActive()) {
			uint8_t Mode_ = atoi(outputgroup_->_ModeValue);
			uint8_t Count_ = atoi(outputgroup_->_NumberValue);
			uint16_t Address_ = atoi(outputgroup_->_AddressValue);
			uint8_t TimeOn_ = atoi(outputgroup_->_TimeOnValue);
			uint8_t TimeOff_ = atoi(outputgroup_->_TimeOffValue);
			uint8_t Multiplier_ = atoi(outputgroup_->_MultiplierValue); // Multiplikator
			uint8_t TimeOnFade_ = atoi(outputgroup_->_TimeOnFadeValue);
			uint8_t TimeOffFade_ = atoi(outputgroup_->_TimeOffFadeValue);
			uint8_t Brightness_ = atoi(outputgroup_->_BrightnessValue);

			uint16_t DayLightAddress_ = 0;
			uint8_t DayBrightness_ = 255;
			uint8_t NightBrightness_ = 150;

			SoundSettings sound_;
			sound_.filename = outputgroup_->getSoundFilename();
			sound_.volume = soundGroup.getVolume();
			sound_.balance = soundGroup.getBalance();
			sound_.mono = soundGroup.isMono();

			Serial.print(F("Values for channel ")); Serial.print(channel_); Serial.println(F(" preserved"));
			Serial.print(F("    Channels used: ")); Serial.println(Count_);
			Serial.print(F("    Address: ")); Serial.println(Address_);

			// Einrichten des Ports
			accessories* newAccessory = nullptr;
			switch (Mode_) {
			case 0:
				newAccessory = new accessories(Address_, channel_);
				channel_ += Count_;
				break;
			case 40: // einfacher Ausgang
				newAccessory = new Ausgang(Address_, channel_);
				channel_ += 1;
				break;
			case 50: // Blinker
				newAccessory = new Blinker(Address_, channel_, Multiplier_ * TimeOff_, Multiplier_ * TimeOn_, TimeOnFade_, TimeOffFade_, Mode_);
				channel_ += 1;
				break;
			case 51: // Wechselblinker
				newAccessory = new Wechselblinker(Address_, channel_, Multiplier_ * TimeOff_, Multiplier_ * TimeOn_, TimeOnFade_, TimeOffFade_);
				channel_ += 2;
				break;
			case 80: // TV
				newAccessory = new Fernseher(Address_, channel_);
				channel_ += 1;
				break;
			case 81: // Schweisslicht
				newAccessory = new Schweissen(Address_, channel_, Multiplier_ * TimeOff_, Multiplier_ * TimeOn_);
				channel_ += 3;
				break;
			case 82: // Feuer
				newAccessory = new Feuer(Address_, channel_);
				channel_ += 3;
				break;
			case 83: // Blitzlicht
				newAccessory = new Blitzlicht(Address_, channel_, TimeOnFade_ * 1000, TimeOffFade_ * 1000, TimeOn_ * Multiplier_, TimeOff_ * Multiplier_);
				channel_ += 1;
				break;
			case 203:// Motor
				newAccessory = new Motor(Address_, Mode_); // Create a new Motor accessory
				break;
			}

			if (newAccessory != nullptr) {
				Serial.print(F("    Mode: ")); Serial.println(Mode_);

				newAccessory->setSoundSettings(sound_);
				//newAccessory->setInputPin(outputgroup_->getInputPin());
				newAccessory->setTimer(outputgroup_->getActiveDuration());

				// Check the type of newAccessory
				if (newAccessory->getType() == AccessoryType::LED) {
					Ausgang* ledAccessory = static_cast<Ausgang*>(newAccessory);
					// If the cast is successful, set the brightness
					ledAccessory->SetMaxBrightness(Brightness_);
				}
				decoder.PushBack(newAccessory);
			}
		}
		outputgroup_ = (OutputGroup*)outputgroup_->getNext();
	}

	ServoGroup* servogroup_ = &ServoGroup1;
	while (servogroup_ != nullptr) {
		if (channel_ > 15) {
			Serial.println("no more free channels!");
			break;
		}

		if (servogroup_->isActive()) {

		}
		servogroup_ = (ServoGroup*)servogroup_->getNext();
	}
}

void setup() {
	Serial.begin(115200);
	while (!Serial) {
		delay(10);
	}

	Serial.println("Starting with Firmware " + String(VERSION));

	pinMode(LED_BUILTIN, OUTPUT);
	digitalWrite(LED_BUILTIN, LOW);

	pinMode(INPUT1, INPUT_PULLUP);
	pinMode(INPUT2, INPUT_PULLUP);

	setupWeb(); // Set up web handling

	setupSound(); // Set up sound system

	kDecoderInit(); // Initialize the decoder

}

void loop() {
	loopWeb(); // Handle web requests
	loopSound(); // Handle sound playback

	for (int i_ = 0; i_ < decoder.Size(); i_++) {
		decoder[i_]->process();
		SoundSettings sound_ = decoder[i_]->getSoundSettings();
		if (!sound_.filename.empty()) {
			if (!decoder[i_]->isOn()) {
				// Der Dateiname ist nicht leer, also kann abgespielt werden
				setSoundVolume(sound_.volume);
				setSoundBalance(sound_.balance);
				playSoundLoop(sound_.filename.c_str());
			}
			else {
				stopSound();
			}
		}
	}

	
	
}

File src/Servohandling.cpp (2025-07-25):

// 
// 
// 

#include "Servohandling.h"
#include "pinmapping.h"
#include "common.h"


// ServoAccessory is a class that represents a servo motor accessory.
// It inherits from the Accessory class and provides functionality to control a servo motor.
// It includes methods to initialize the servo, process its state, and control its position.
ServoAccessory::ServoAccessory(uint16_t Address, int8_t ServoPort, int16_t limit1, int16_t limit2, int16_t travelTime) :
	Accessory(Address, ServoPort, 0),
	_ServoPort(ServoPort),
	_limit1(limit1),
	_limit2(limit2),
	_travelTime(travelTime) {
	Serial.println(F("ServoAccessory::ServoAccessory"));
	_servoControl = new ServoControl(ServoPort, limit1, limit2, travelTime);
	off();
}

ServoAccessory::~ServoAccessory() {
	Accessory::~Accessory();
	if (_servoControl) {
		_servoControl->~ServoControl();
		_servoControl = nullptr;
	}
}

void ServoAccessory::process() {
	Accessory::process();
	if (_servoControl) {
		_servoControl->process();
	}
}

void ServoAccessory::on() {
	Accessory::on();
	MoveServo(100); // Move to maximum position
}

void ServoAccessory::off() {
	Accessory::off();
	MoveServo(0); // Move to minimum position
}

void ServoAccessory::MoveServo(uint16_t percentage) {
	Serial.println(F("ServoAccessory::MoveServo()"));
	Serial.print(F("    Percentage: ")); Serial.println(percentage);
	if (_servoControl == nullptr) {
		Serial.println(F("ServoControl is not initialized!"));
		return;
	}

	_servoControl->setPercentPosition(percentage);
}

// ServoImpulseAccessory is a class that represents a servo motor accessory with an impulse feature.
// It inherits from the ServoAccessory class and adds functionality to control the servo for a specific impulse duration.
// after a certain time, the servo will automatically turn off.
ServoImpulseAccessory::ServoImpulseAccessory(uint16_t Address, int8_t ServoPort, int16_t limit1, int16_t limit2, int16_t travelTime, uint16_t impulsTime) :
	ServoAccessory(Address, ServoPort, limit1, limit2, travelTime),
	_impulsTime(impulsTime) {

	if (_impulsTime < travelTime) {
		_impulsTime = travelTime; // Ensure impuls time is at least as long as travel time
	}
}

ServoImpulseAccessory::~ServoImpulseAccessory() {
	ServoAccessory::~ServoAccessory();
}

void ServoImpulseAccessory::process() {
	ServoAccessory::process();
	if (_timer.done() && isOn()) {
		off();
	}
}

void ServoImpulseAccessory::on() {
	Serial.println(F("ServoImpulseAccessory::on()"));
	ServoAccessory::on();
	_timer.start(_impulsTime); // Start the timer for the impulse duration
}

void ServoImpulseAccessory::off() {
	Serial.println(F("ServoImpulseAccessory::off()"));
	ServoAccessory::off();
	_timer.stop();

}

// ServoFlipAccessory is a class that represents a servo motor accessory with a flipping feature.
// It inherits from the ServoAccessory class and provides functionality to control the servo for flipping actions.
// on on the servo will move to one limit, and on off it will move to the other limit.
ServoFlipAccessory::ServoFlipAccessory(uint16_t Address, int8_t ServoPort, int16_t limit1, int16_t limit2, int16_t travelTime) :
	ServoAccessory(Address, ServoPort, limit1, limit2, travelTime) {
	Serial.println(F("ServoFlipAccessory::ServoFlipAccessory()"));
}

ServoFlipAccessory::~ServoFlipAccessory() {
	Serial.println(F("ServoFlipAccessory::~ServoFlipAccessory()"));
	ServoAccessory::~ServoAccessory();
}

void ServoFlipAccessory::process() {
	ServoAccessory::process();
}

void ServoFlipAccessory::on() {
	Serial.println(F("ServoFlipAccessory::on()"));
	ServoAccessory::on();
}

void ServoFlipAccessory::off() {
	Serial.println(F("ServoFlipAccessory::off()"));
	ServoAccessory::off();
}

ServoPendelAccessory::ServoPendelAccessory(uint16_t Address, int8_t ServoPort, int16_t limit1, int16_t limit2, int16_t travelTime, uint16_t pendelTime) :
	ServoAccessory(Address, ServoPort, limit1, limit2, travelTime),
	_onTime(pendelTime)
{
	Serial.println(F("ServoPendelAccessory::ServoPendelAccessory()"));
	if (_onTime < travelTime) {
		_onTime = travelTime; // Ensure pendulum time is at least as long as travel time
	}
	_offTime = _onTime; // Set off time to the same value initially
	_direction = true;
	

}

ServoPendelAccessory::ServoPendelAccessory(uint16_t Address, int8_t ServoPort, int16_t limit1, int16_t limit2, int16_t travelTime, uint16_t onTime, uint16_t offTime) :
	ServoAccessory(Address, ServoPort, limit1, limit2, travelTime),
	_onTime(onTime),
	_offTime(offTime)
{
	Serial.println(F("ServoPendelAccessory::ServoPendelAccessory()"));

	if (_onTime < travelTime) {
		_onTime = travelTime; // Ensure on time is at least as long as travel time
	}
	if (_offTime < travelTime) {
		_offTime = travelTime; // Ensure off time is at least as long as travel time
	}
	_direction = true;

	Serial.print(F("    onTime: ")); Serial.println(_onTime);
	Serial.print(F("    offTime: ")); Serial.println(_offTime);

}


ServoPendelAccessory::~ServoPendelAccessory() {
	Serial.println(F("ServoPendelAccessory::~ServoPendelAccessory()"));
	ServoAccessory::~ServoAccessory();
}

void ServoPendelAccessory::process() {
	ServoAccessory::process();

	if (isOn()) {
		if (_timerPendel.done() || !_started) {
			_started = true; // Mark that the pendulum has started moving

			// Set position: 0% for one direction, 100% for the other
			if (_direction) {
				MoveServo(100); // Move to _limit2
				_timerPendel.start(_onTime); // Start with _onTime
			}
			else {
				MoveServo(0);  // Move to _limit1
				_timerPendel.start(_offTime); // Start with _offTime
			}
			_direction = !_direction;
		}
	}
}

void ServoPendelAccessory::on() {
	Serial.println(F("ServoPendelAccessory::on()"));
	IsActive = true; // Set the accessory to active state
	_timerPendel.start(_onTime); // Start the timer for pendulum movement
	_started = false;
}

void ServoPendelAccessory::off() {
	Serial.println(F("ServoPendelAccessory::off()"));
	IsActive = false; // Set the accessory to inactive state
	_timerPendel.stop(); // Stop the timer when turned off

}

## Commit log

2025-07-05 Update readme.md to include detailed pin mapping and controller information
2025-07-05 initial version
    [KirmesKontroller.brd, KirmesKontroller.sch]
2025-07-05 fix: indexes changed
    [KirmesKontroller.brd, KirmesKontroller.sch]
2025-07-05 feat: add LEDControl classes for LED management and control
2025-07-05 feat: add MotorControl classes for motor management and control
2025-07-05 refactor: remove MotorControl class and its associated header file
2025-07-06 initial upload
    [KirmesKontroller.brd, KirmesKontroller.sch]
2025-07-06 fix: update GPIO channel mapping and definitions in pinmapping.h
    [pinmapping.h]
2025-07-10 Version 1.0
    [KirmesKontroller.brd, KirmesKontroller.sch]
2025-07-10 docs: add schema and board images to README
2025-07-10 fix: update LED controlapi for esp 3.x
    [LEDControl.cpp, LEDControl.h]
2025-07-10 refactor: improve Motor class implementation and add PWM frequency handling
2025-07-12 fixed pinmapping
    [KirmesKontroller.brd, KirmesKontroller.sch]
2025-07-12 fix: correct INPUT1 and INPUT2 pin definitions in pinmapping.h
    [pinmapping.h]
2025-07-12 fix: correct sound setup function name and restore sound playback logic
    [KirmesKontroller.ino]
2025-07-12 fix: update pin mapping and library references in the README
2025-07-12 feat: add Blinker and LED control classes with various modes and functionalities
2025-07-12 feat: enhance kDecoderReset to apply default values for additional parameters in output and servo groups
2025-07-12 feat: enhance Motor class methods to ensure accessory state management during on/off and process operations
2025-07-12 feat: enhance accessories class with input pin management and timer functionality
2025-07-13 feat: fix initialization of Mode and correct logical condition in process method
    [accessories.cpp]
2025-07-13 fix: update parameter access in kDecoderReset and kDecoderInit for consistency
    [KirmesKontroller.ino]
2025-07-13 feat: override methods in Motor class for consistency with base class
2025-07-13 fix: update NUMBER_LEN definition and add input pin values and names
2025-07-13 feat: enhance process and timer management in accessories class with detailed logging
2025-07-13 feat: add Input Pin parameter to SoundGroup class for enhanced configuration
2025-07-13 fix: simplify ON_LEVEL definition for consistent behavior across ESP32
    [webhandling.cpp]
2025-07-13 fix: add missing logging statements in MotorControl destructor and methods
    [MotorControl.cpp]
2025-07-13 fix: correct boundary check in DecoderGroupIsActive and streamline kDecoderInit logic
    [KirmesKontroller.ino]
2025-07-13 fix: update pin mapping for consistency and clarity
    [pinmapping.h]
2025-07-13 fix: add brightness label to hideClass function for improved UI clarity
    [html.h]
2025-07-13 feat: streamline decoder reset logic and enhance task handling in setup
    [KirmesKontroller.ino]
2025-07-13 fix: enhance input processing logic in accessories class for better state management
    [accessories.cpp]
2025-07-14 fix: add process and on method overrides in various classes for improved functionality
    [Blinkers.cpp]
2025-07-14 feat: implement NMRA handling functions and factory default reset logic
    [NMRAhandling.cpp]
2025-07-14 fix: correct size of ChannelToGPIOMapping array to match defined GPIO channels
    [pinmapping.h]
2025-07-14 fix: comment out debug print statements in audio_info and audio_id3data functions
    [SoundControl.cpp]
2025-07-14 pin 47 named
    [KirmesKontroller.brd, KirmesKontroller.sch]
2025-07-14 fix: change setTimer parameter type from int16_t to uint16_t for better clarity
    [accessories.cpp]
2025-07-14 fix: uncomment kDecoderInit call in setup for decoder initialization
    [KirmesKontroller.ino]
2025-07-14 fix: remove unused variable declarations in html.h for cleaner code
    [html.h]
2025-07-14 fix: add newline for better readability in Accessory::on method
    [accessories.cpp]
2025-07-14 feat: add start delay functionality to Motor class for controlled activation
2025-07-14 fix: improve file existence check and error handling in playSound function
    [SoundControl.cpp]
2025-07-14 feat: enhance Motor accessory initialization with time-based activation
2025-07-15 fix: execute filename validation logic only when group is active
    [webhandling.cpp]
2025-07-16 feat: added ESPServo and ServoControl classes for servo management
2025-07-17 feat: refactor ServoGroup and OutputGroup to AccessoryGroup and enhance parameter handling
2025-07-18 feat: add ServoModeValues and ServoModeNames for servo control functionality
2025-07-18 feat: add Mode parameter to ServoGroup for enhanced control options
2025-07-18 feat: enable ServoGroup parameters in web configuration setup
2025-07-18 feat: update ServoModeNames to replace 'Zyklus' with 'Pendel' for clarity
2025-07-18 feat: reorder ServoGroup parameter additions in setupWeb for improved clarity
2025-07-18 feat: add ServoModes header file with accessory classes for servo control
2025-07-18 fix: correct include for ServoModes and clean up comments in kDecoderInit
    [KirmesKontroller.ino]
2025-07-19 feat: update ServoModeValues to include new range for servo control
2025-07-19 feat: add servo group initialization with timeOn and timeOff parameters
2025-07-19 refactor: update OutputGroup and ServoGroup accessors for improved clarity
2025-07-19 refactor: replace direct member access with getter methods in kDecoderInit for OutputGroup
    [KirmesKontroller.ino]
2025-07-20 refactor: update ChannelToGPIOMapping size and add ServoChannelToGPIOMapping
2025-07-20 refactor: update ServoModeNames values to match corresponding modes
2025-07-20 refactor: correct size of ChannelToGPIOMapping array and adjust formatting
    [pinmapping.h]
2025-07-20 refactor: improve servo mode handling in kDecoderInit
2025-07-21 refactor: switched to new, external library
2025-07-21 refactor: update ServoControl to use new ESP32Servo and improve interval handling
2025-07-21 refactor: enhance ServoAccessory and ServoPendelAccessory for improved logging and control flow
2025-07-21 refactor: update kDecoderInit to improve servo handling and preserve values
2025-07-23 feat: add ServoBounce class for enhanced servo bouncing functionality
2025-07-23 feat: add repeatdone method and enhance timer reset functionality
2025-07-23 refactor: standardize method naming conventions in ServoControl class
2025-07-23 refactor: improve ServoControl class by standardizing method names and enhancing flag handling
2025-07-23 refactor: remove unused variables from ServoControl class
2025-07-23 fix: correct variable name typos and improve logging in ServoControl class
    [ServoControl.cpp]
2025-07-23 fix: correct typos in variable names related to target position in ServoControl class
2025-07-24 fix: correct variable name typos in ServoControl class
    [ServoControl.cpp]
2025-07-24 refactor: clean up process method in ServoBounce class by removing commented-out code
2025-07-24 fix: update servo initialization constants and enhance ServoBounce constructor with additional flags
2025-07-24 refactor: improve code structure and readability in ServoControl class
2025-07-24 fix: enhance initialization logging in ServoControl constructor for better debugging
    [ServoControl.cpp]
2025-07-24 fix: correct channel variable in kDecoderInit function for proper servo setup
    [KirmesKontroller.ino]
2025-07-24 fix: update MoveServo method to use setPercentPosition for improved clarity
    [Servohandling.cpp]
2025-07-24 fix: streamline index increment logic in handleData function
    [webhandling.cpp]
2025-07-24 fix: comment out debug logging in handleData function for cleaner output
    [webhandling.cpp]
2025-07-24 fix: change Serial.print to Serial.println
    [KirmesKontroller.ino]
2025-07-25 fix: change Serial.print to Serial.println for setInputPin and setTimer methods
    [accessories.cpp]
2025-07-25 fix: reorder initialization of limits and interval time in ServoControl constructor
    [ServoControl.cpp]
2025-07-25 fix: ensure proper destruction and processing in ServoAccessory and ServoPendelAccessory classes
    [Servohandling.cpp]
2025-07-25 fix: add sound settings handling in kDecoderInit function
    [KirmesKontroller.ino]
2025-07-25 refactor: move Motor class implementation to separate Motorhandling files
2025-07-25 fix: update button styles and improve form submission handling in HTML
    [html.h]
2025-07-25 fix: update button behavior and styling in handleRoot function
    [webhandling.cpp]
2025-07-25 fix: reorder include statements for consistency and clarity
    [KirmesKontroller.ino]
2025-07-25 fix: adjust input handling in Accessory class and update pin mode configuration
    [accessories.cpp]
2025-07-25 fix: simplify MoveServo method and add getServoTenthsPosition for servo position retrieval
2025-07-25 fix: simplify MoveServo method by removing unnecessary parameters and improve servo control logic
    [Servohandling.cpp]
2025-07-26 fix: reorganize LED class member variables for improved clarity and structure
    [LEDControl.h]
2025-07-26 fix: enhance LED class with attach/detach methods and streamline write logic
    [LEDControl.cpp]
2025-07-26 fix: update Accessory class for improved input handling and configuration
    [accessories.cpp]
2025-07-26 fix: update Ausgang and Blinker classes to improve process and state management
    [Outputhandling.cpp]
2025-07-26 fix: enhance kDecoderInit function with initialization logs and memory management
    [KirmesKontroller.ino]
2025-07-26 fix: add debug logs in destructors for LED and LEDFader classes
    [LEDControl.cpp]
2025-07-26 fix: make destructors virtual in LED, LEDFader, Natrium, and Neon classes for proper cleanup
    [LEDControl.h]
2025-07-26 fix: refactor LED and LEDFader constructors to use 'pin' parameter and improve PWM channel management
    [LEDControl.cpp, LEDControl.h]
2025-07-26 fix: rename ChannelToGPIOMapping and ServoChannelToGPIOMapping for clarity and consistency
    [pinmapping.h]
2025-07-26 fix: refactor MotorControl class to improve constructor parameters and enhance attach/detach functionality
    [MotorControl.cpp]
2025-07-26 fix: update constructor parameters in Ausgang and Blinker classes for consistency and clarity
    [Outputhandling.cpp]
2025-07-26 feat: add PWMChannelManager class for managing PWM channels
2025-07-26 feat: ESP32PWM for LED controlling and proper channel management
2025-07-26 fix: refactor kDecoderInit for improved clarity and consistency in channel management
    [KirmesKontroller.ino]
2025-07-26 fix: update comment formatting for consistency in notification defines
    [KirmesKontroller.ino]
2025-07-26 refactor: remove PWMChannelManager class and its implementation files
2025-07-27 fix: update visibility arrays to include additional values for timeon and multiplier
    [html.h]
2025-07-27 fix: update getNumber method to handle specific cases and improve output parameter naming
    [webhandling.cpp]
2025-07-27 fix: update accessory initialization to use AusgangDelay for improved timing handling
    [KirmesKontroller.ino]
2025-07-27 fix: clean up destructor implementations and improve memory management in various classes
    [Outputhandling.cpp]
2025-07-27 fix: enhance form validation and output handling in web handling module
    [webhandling.cpp]
2025-07-27 fix: add support for new accessory types in decoder initialization
    [KirmesKontroller.ino]
